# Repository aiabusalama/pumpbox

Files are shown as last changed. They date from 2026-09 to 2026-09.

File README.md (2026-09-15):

# REISBOT Pump Guard

A small box that keeps a solar-powered water pump alive. Rust on a Raspberry Pi Zero W.

## The problem

The pump is a 138 V, 1.5 kW DC brushless submersible (110–150 V range, 11 A max). Its own controller card
is destroyed above 150 V. The array is three GSE-HC455 panels in series: 150.9 V open-circuit at 25 °C, and
climbing toward 165 V on a cold morning — exactly the voltage present at sunrise, before any current flows.
That killed the first controller card. The second time it could not be repaired.

## What the box does

- Watches the array voltage and current every few milliseconds (PZEM-017 over RS-485).
- Keeps the contactor open until the array has settled inside the safe window (95–145 V), and drops it
  again on over-voltage, under-voltage, over-current, a dry well, or loss of contact with the meter.
- Waits, re-checks that the voltage is steady (about 15 s), and restarts by itself.
- Runs the pump from the water levels: a level relay in the well, another in the tank.
- Shows everything on a 20×4 LCD, one status light (blinking = ready, solid = running, two flashes =
  too high, three = too low) and a phone dashboard over its own Wi-Fi hotspot.

## Parts

| Part | Role |
|---|---|
| Raspberry Pi Zero W | the brain, runs `pumpd` |
| PZEM-017 + 50 A shunt | volts, amps, watts on the pump line |
| Schneider contactor | switches the 150 V DC pump line |
| 5 V relay module | drives the contactor coil from the Pi |
| HLK-10M24 | 143 V → 24 V for the contactor coil |
| 5 V / 3 W supply | the Pi |
| 12 V converter | feeds the two level relays |
| 2 × SSRC-04 level relays | well and tank levels — sold for 220 V AC, bypassed to run on 12 V DC (two jumper wires) |
| 20×4 I²C LCD, mode switch, START / STOP buttons | the front panel |

## Repo layout

- `rust/` — `pumpd`, the controller: state machine, PZEM-017 meter, front panel, LCD, watchdog, fail-safe,
  web dashboard. `rust/src/bin/` holds two bench tools (`failprobe`, `wdtest`).
- `kicad/level/` — the level-sensor board (schematic, PCB, etch transfers, drill file, wire-link map); `kicad/render/`
  shows the finished board; `kicad/BOM.txt` is the sourcing list.
- `hotspot/` — the Pi's Wi-Fi hotspot: setup script, captive-portal responder, watchdog units.
- `fritzing/`, `qet/` — wiring sketch and electrical diagram.
- `docs/` — enclosure layout and wiring pages; `DESIGN.md` and `BUILD.md` — design notes and build guide.

## Disclaimer

This is a personal hobby project, built for one farm and shared as-is. It is not a product, it is not certified,
and it is not affiliated with or endorsed by any employer or manufacturer. It switches 150 V DC, which can injure
or kill: if you copy any of it, you take full responsibility for your own installation, and you should have a
qualified electrician check it. No warranty of any kind — see the licence.

## Licence

MIT

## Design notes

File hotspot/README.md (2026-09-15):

# Field hotspot

The pump box has to be commissioned at a site with **no router, no WiFi and no
usable mobile data**, with **only a phone**. Nothing in the rest of this repo
gets you a network there: `BUILD.md` assumes the Pi already joined a WiFi you
control and tells you to browse to `http://<pi-address>:8080`. At the field
site there is no such address and no way to discover one.

This directory makes the Pi **its own access point**, so the phone joins the
box directly.

```
    SSID       PumpBox
    PASSWORD   ReisLandPump2026
    DASHBOARD  http://192.168.4.1:8080/
```

Change any of that in [`hotspot.conf`](hotspot.conf) and re-run the script.

---

## Run it

**At home, over SSH, before the trip.** It needs internet once, for
`dnsmasq-base`.

```bash
cd ~/automations/pump/hotspot     # wherever deploy.sh put the repo
sudo bash setup-hotspot.sh
```

Then the only test that counts:

```bash
sudo reboot
# ...with your home router powered OFF...
sudo bash setup-hotspot.sh --status
```

| Command | Effect |
|---|---|
| `sudo bash setup-hotspot.sh` | configure and activate |
| `sudo bash setup-hotspot.sh --status` | report only, changes nothing, no root needed |
| `sudo bash setup-hotspot.sh --no-activate` | configure, apply on next reboot |
| `sudo bash setup-hotspot.sh --undo` | remove everything it installed |

It is idempotent. Re-running converges the machine rather than stacking
changes, so it is safe to run after editing `hotspot.conf`, and safe to run on
a box you are not sure about.

If you run it **while connected over the hotspot itself**, it notices (your
`SSH_CONNECTION` source is in the AP subnet) and defers activation rather than
cutting the session out from under you. Reboot to apply.

---

## What it does

**One NetworkManager profile.** Not hostapd + dnsmasq. Bookworm made
NetworkManager the only network stack on every image including Lite — `dhcpcd`
and `/etc/network/interfaces` are gone, so the static-IP half of every older
tutorial silently does nothing, and NM keeps managing `wlan0` and fights
hostapd for it. NM's AP mode drives the same wpa_supplicant code path and
spawns its own scoped dnsmasq for DHCP. One profile, no second daemon stack,
which matters on a 512 MB single core.

Specifically:

| | |
|---|---|
| **Packages** | Installs `dnsmasq-base`, `iw`, `rfkill`. Holds and disables the full `dnsmasq` **daemon** — it binds `:53` system-wide and collides with the private instance NM spawns for shared mode. |
| **Regulatory domain** | Three ways: `/etc/modprobe.d/pump-ap-regdom.conf`, `raspi-config nonint do_wifi_country`, and `pump-ap-regdom.service` re-asserting at boot before NM. Pi OS keeps WLAN rfkill soft-blocked until a country is set, and the failure is silent — the profile activates "successfully" and no SSID is ever transmitted. |
| **Competing profiles** | Sets `autoconnect no` on every *other* WiFi profile, by enumerating real names. Raspberry Pi Imager's WiFi customisation creates one called **`preconfigured`**, so guides that say "set your home profile to autoconnect no" name something that does not exist — and the bench rehearsal then quietly runs on home WiFi, which is the one thing it exists to disprove. |
| **AP profile** | `pump-ap`: AP mode, band bg, fixed channel, `ipv4.method shared`, `192.168.4.1/24`, IPv6 off, `autoconnect-priority 100`, `autoconnect-retries 0` (retry forever). |
| **Watchdog** | `pump-ap-watchdog.timer` every 2 min. Brings the AP up **only if `wlan0` has no active connection**, so it recovers a dead AP without yanking you off home WiFi mid-`apt` at the bench. |
| **Boot diagnostics** | `pump-ap-diagnostics.service` appends the network state to `/boot/firmware/pumpnet.log` on every boot. |
| **Captive portal** | Answers Android/Apple connectivity probes so the phone stops nagging and stops routing your request out the cellular interface. Own process, port 80. |
| **Boot speed** | Disables `NetworkManager-wait-online.service`, which can stall boot 45 s waiting for a network that will never exist at the site. |

### Why `192.168.4.1` and not NM's default `10.42.0.1`

Turkish carriers hand out CGNAT addresses inside RFC1918 `10.0.0.0/8`. A phone
holding a `10.x` cellular route can send `10.42.0.1` out the LTE interface
instead of the WiFi one, and the symptom is indistinguishable from a dead Pi.
`192.168.4.0/24` has no such overlap.

If you have seen `10.42.0.1` written on an earlier version of the field card or
the lid label, **it is wrong** — fix it before printing.

---

## On the phone

**In this order. The first step is not optional.**

1. **Airplane mode ON, then WiFi back ON.**
2. Join `PumpBox`.
3. Browser: **`http://192.168.4.1:8080/`** — type the `http://`.

Airplane mode first is the guarantee, not a superstition. Android probes
`http://connectivitycheck.gstatic.com/generate_204` over a candidate network;
with no upstream that fails, the network is marked unvalidated, and the failure
mode is usually **not** "WiFi disconnects" — it is "WiFi stays connected but
the browser's request to the Pi leaves via LTE and dies." With the cellular
radio off there is no alternative route and the whole class of problem is gone.
There is no usable data at the site anyway.

Also set once, at home:

- **Private DNS → Off.** A DoT hostname makes the phone bypass the Pi's dnsmasq
  entirely.
- **Adaptive Connectivity / "switch to mobile data automatically" → Off.** Name
  varies by vendor. This is the setting that actively drops a no-internet WiFi.
- When "This network has no internet access. Stay connected?" appears, tick
  **"Don't ask again for this network"** and tap **Yes**.

Type the `http://`. Chrome hands a bare `192.168.4.1:8080` to the search engine
often enough to matter, and the search fails because there is no internet.

### Do not rely on `raspberrypi.local`

`BUILD.md` offers it "if your phone supports mDNS". Android has never reliably
resolved `.local` from a browser. The AP address is static by construction, so
mDNS buys nothing and can only produce a confusing failure at the worst moment.

### Print this for inside the lid

```
SSID       PumpBox
PASSWORD   ReisLandPump2026
DASHBOARD  http://192.168.4.1:8080/
```

Add two QR codes on the same A4 sheet — one
`WIFI:T:WPA;S:PumpBox;P:ReisLandPump2026;;` (the Android camera joins from it,
no typing) and one `http://192.168.4.1:8080/`. Typing a 16-character password
on a phone in field sunlight eats twenty minutes.

---

## Verifying the AP is up

### From the box, with a shell

```bash
sudo bash setup-hotspot.sh --status
```

The four lines that matter:

| Line | Good | Bad |
|---|---|---|
| regulatory domain | `country TR:` | `country 00: DFS-UNSET` → **AP transmits nothing** |
| rfkill | both blocks `no` | `Soft blocked: yes` → no country set |
| Active on wlan0 | `pump-ap` | *nothing active* → AP is down |
| Attached phones | `1` after you join | `0` → association or DHCP failed |

### From the phone, with no app and no shell

**Look at the phone's own IP.** Settings → WiFi → `PumpBox` → details.

- **`192.168.4.x`** — radio *and* DHCP both work. Any remaining problem is the
  web service or Android routing (go back and do airplane mode).
- **`169.254.x.x` or no address** — association succeeded, **DHCP failed**.
  That is `dnsmasq-base` missing or NM's dnsmasq refusing to start. This is the
  only way to see that failure without a shell, and it is the single most
  likely silent one.
- **Not in the WiFi list at all** — the regulatory domain, almost certainly.

### From the LCD

Currently: **you cannot.** See the known-issues section below — the LCD will
show a blank address line even when the AP is perfectly healthy. That is a bug
in `pump_control.py`, not in this directory, and it is not fixed here.

---

## Undo

```bash
sudo bash setup-hotspot.sh --undo
```

Removes the units, the AP profile, the dnsmasq drop-in, the modprobe file and
the installed helpers, and restarts NetworkManager.

It deliberately does **not** re-enable your other WiFi profiles — it has no way
to know which of them you wanted autoconnecting. Put your home network back
with:

```bash
nmcli connection modify preconfigured connection.autoconnect yes
```

### Getting on home WiFi temporarily without undoing anything

At the bench, to run `apt` or `deploy.sh`:

```bash
sudo touch /run/pump-ap-inhibit          # stop the watchdog reclaiming the radio
sudo nmcli connection up preconfigured   # or whatever `nmcli con show` calls it
```

`/run` is tmpfs, so **any reboot clears the inhibit and returns to the AP.**
There is no state in which you can strand yourself. To come back without
rebooting:

```bash
sudo rm /run/pump-ap-inhibit
sudo nmcli connection up pump-ap
```

---

## When the phone will not associate

Work down this list. Each step is one edit to `hotspot.conf` and a re-run.

1. **`PMF="1"`** (the shipped default). NM's default resolves to
   PMF-*optional* for `wpa-psk`, so the AP advertises 802.11w-capable.
   brcmfmac's AP path handles 802.11w poorly and a failed negotiation surfaces
   on Android as **"incorrect password"**. This is the leading suspect.
2. **`STRICT_CIPHERS="no"`** (the shipped default) leaves `proto`, `pairwise`
   and `group` unset, which is what NetworkManager's own documentation
   recommends for maximum compatibility. Try `"yes"` (WPA2-AES pinned) if
   loose fails — the field evidence is genuinely contradictory, one Raspberry
   Pi forum thread reports Android working only after *removing* the pinning
   and an Arch thread reports the exact opposite.
3. **`CHANNEL`** → try `1` or `11`.
4. **`PSK=""`** — an open, unencrypted AP. Last resort, and a legitimate one:
   the box is on private family land and its only exposed control sits behind a
   143 V DC contactor. An unencrypted dashboard beats an unreachable one.

> There is a published report of a **Zero W on 32-bit Bookworm** whose
> NetworkManager AP refuses Android with "password incorrect" while Windows and
> Linux connect fine. **Test with the actual phone you are taking.** A laptop
> associating proves nothing about this failure.

## Do not run Trixie on this board

Pi OS 13 (Trixie) **cannot bring up a WPA-protected nmcli hotspot on an
original Pi Zero W.** Activation dies with `802.1X supplicant took too long to
authenticate` and the kernel logs `key setting validation failed` from
brcmfmac. Upstream issue [raspberrypi/linux#7247][7247] is open with no
workaround. Open hotspots still come up; adding `wpa-psk` kills it.

Use **Raspberry Pi OS 12 (Bookworm) Lite, 32-bit**. The Zero W is ARMv6 and
cannot run a 64-bit image at all. Confirm with `cat /etc/os-release` →
`VERSION_ID="12"`. The script warns if it sees anything else.

Do not `apt full-upgrade` across a release before the trip. If you want to be
strict about it, Bookworm's own security pocket can still move the two packages
implicated in that bug:

```bash
sudo apt-mark hold network-manager wpasupplicant
```

The script does **not** do this for you — it blocks security updates, and that
is your call, not the script's.

## Do not run AP and home WiFi at the same time

One radio, one channel. The AP gets forced onto whatever channel the router
picked; throughput roughly halves; and brcmfmac's AP+STA combination on the
BCM43438 is the least-exercised path in the driver — on the same board that
already cannot complete a plain WPA hotspot on Trixie. You would be stacking
your only access on the flakiest available configuration, to gain nothing: at
the field site there is no other network for the client half to join.

Two profiles, AP always wins a reboot. That is what the script sets up.

---

## Phone-only recovery, when the AP is dead

**Triage on the LCD first**, because it splits the problem cleanly:

- **LCD blank** → power, boot or SD card. Not a network problem.
- **LCD shows STANDBY with live volts** → the controller is alive and
  protecting. This is *purely* a WiFi problem. **The pump is safe. You can stop
  here and tune the dashboard another day.** `BUILD.md` Stage 6 needs 2–3 days
  of history before dry-run tuning is meaningful, so the dashboard is genuinely
  not needed on day one. The real risk at this point is you poking at a working
  protection box.

Then, in order:

1. Wait a full 90 s. NM can be slow to bring up AP mode on this board.
2. Power-cycle once. The watchdog retries every 2 minutes after that.
3. Phone: forget the network, rescan. Confirm airplane mode is on.
4. **Swap to the spare SD card.** This is the recovery mechanism.
5. Only then, power down and read `/boot/firmware/pumpnet.log` on the phone via
   an OTG card reader, to learn *which* card to blame.

### Why the log is read-only and there is no editable config on the boot partition

An earlier plan for this box proposed a `/boot/firmware/pumpnet.conf` you could
edit from the phone to fix the AP in the field. **That is not a phone
procedure.** Executing it costs: open the DC breaker (pump stops), unscrew the
IP65 lid, unplug the Pi from the LM2596 and the USB-RS485 cable, extract a
microSD that protrudes about a millimetre from a Zero W's friction slot, plug
in an OTG reader, edit, reinsert, reassemble, re-energize — and it is
edit-reboot-repeat, so **every hypothesis costs a full disassembly cycle.**

Worse, a Pi OS card has a FAT32 boot partition and an ext4 root, and some
Android builds respond to that by offering to "fix" the **corrupted USB drive**
— tapping it formats the card you were trying to rescue.

So: reading the log **once** is a plausible field action and is supported. The
fix for a dead AP is **the spare SD card**, not an editor. Prepare two
identical cards and verify both boot before you leave. You cannot write a disk
image from stock Android; if both cards fail on site, the trip is over.

If you do want an in-field AP override, make it **physical** — a jumper on a
spare GPIO, read at boot, forcing an open no-password AP on channel 6. That
bypasses every failure a config file guards against (wrong PSK, wrong channel,
wrong regdomain) without opening anything. Not implemented here.

### The one thing on the boot partition you *can* usefully change from a phone

The regulatory domain is also settable as a kernel parameter, by appending this
to the single line in `/boot/firmware/cmdline.txt`:

```
cfg80211.ieee80211_regdom=TR
```

`cmdline.txt` is on the FAT partition, so it is reachable over an OTG reader,
and a missing country code is the highest-probability AP failure. Worth writing
on the lid label next to the SSID.

**Caveat, stated plainly:** this script does *not* write that line, because
whether a kernel-command-line module parameter is honoured for `cfg80211` when
it loads as a module is exactly the sort of thing that must be checked on the
hardware rather than assumed. The script uses `/etc/modprobe.d` and a boot-time
`iw reg set` instead, both of which are unambiguous. Treat the `cmdline.txt`
line as an unverified emergency lever: it will not hurt, and it may help.

---

## Known issues in the rest of the repo that this directory does not fix

These are real, they bite specifically in AP mode, and they are **not** touched
here because this task was scoped to the hotspot. Fix them before the trip.

**1. The LCD will never show you the address.** `pump_control.py:22-31`:

```python
s.connect(("192.0.2.1", 1))       # TEST-NET-1, never routed
ip = s.getsockname()[0]
```

That works by asking the kernel which source address a route to an arbitrary
destination would use. `ipv4.method=shared` installs **only** the on-link
`192.168.4.0/24` route and **no default route** — correctly, there is no
upstream. So `connect()` fails with `ENETUNREACH`, `except OSError` returns
`None`, and the LCD's address line renders as `""` or `waiting for band`. You
stand at the box with a working hotspot and a screen telling you nothing.

Read the interface instead of the routing table — `SIOCGIFADDR` via `fcntl`, or
`ip -4 -o addr show wlan0`. Note that `install.sh:70` already uses the AP-safe
incantation (`hostname -I`); the broken one is in `pump_control.py`. The fix is
already in this repo, in the wrong file.

**2. The address is read once, at startup.** `pump_control.py:44` calls
`local_ip()` in `App.__init__`. On a cold boot the protection service easily
wins the race against NetworkManager, caches `None`, and never re-checks for
the rest of the day. Re-read it on a slow cadence — every ~10 s from the main
loop, into a cached string, never raising into the loop.

**3. A dashboard that cannot bind permanently stops the pump.**
`pump_control.py:45` calls `web.start(self.controller)` unguarded, and
`web.py:285` binds `0.0.0.0:8080`. If that raises — a lingering process after a
crash-restart, say — it propagates out of `App()`, `main()` returns 1, and
systemd's `Restart=always` retries every 5 s forever with the contactor open.
Wrap it:

```python
try:
    self.server = web.start(self.controller)
except OSError as e:
    log(f"dashboard unavailable: {e}")
    self.server = None
```

and make `shutdown()` tolerate `self.server is None`.

**4. Do not add `iw dev wlan0 station dump` to the control loop.** If you add a
client count to the LCD, read the lease files
(`/var/lib/NetworkManager/dnsmasq-*.leases`) — O(1), non-blocking. A subprocess
inside a 0.5 s loop on a single-core 512 MB board stalls `controller.update()`
and blinds the protection for its duration. If you must shell out, do it on the
web thread.

**5. Leave `pump-protection.service` at `After=network.target`.** Do not add
`Wants=`/`Requires=NetworkManager.service` or `network-online.target`. The pump
must come up on a box whose radio is dead. The script asserts this on every
run and refuses to finish if something has added such a line.

---

## Nothing here has been run on hardware

The Pi is not wired yet. Be precise about what that means.

**Verified off-hardware, on the workstation:**

- Every property in the profile is accepted by `nmcli --offline connection add`
  (nmcli 1.50) and emits the intended keyfile. Every property used dates to
  nmcli ≤ 1.4, so Bookworm's 1.42 accepts it.
- Clearing `proto`/`pairwise`/`group` with `""` produces a keyfile with those
  keys absent; empty `key-mgmt` produces one with no `[wifi-security]` section
  at all. Both compatibility fallbacks are real.
- `man nmcli` EXIT STATUS: **3 = timeout, 4 = connection activation failed.**
  Widely copied recipes have these swapped and mark a real activation failure
  as success. `pump-ap-ensure.sh` maps them correctly.
- `portal-responder.py`: 204 on `/generate_204` and `/gen_204` with no
  `Content-Length` (RFC 7230), the exact Apple success body on
  `/hotspot-detect.html`, 302 to the dashboard for everything else, HTTP/1.1
  keep-alive across all three, and a second instance losing port 80 exits 0
  instead of restart-looping.
- `pump-ap-ensure.sh` decision paths: already-up, another-connection-owns-the
  interface, inhibit-file, activation-failure. All behave.
- `pump-ap-diagnostics.sh` produces a useful log and caps its own size.
- All shell files pass `bash -n`; the Python compiles.

**NOT verified, and only the hardware can settle it:**

| | |
|---|---|
| **That an Android phone associates at all** | The highest-risk item by a distance. There is a published report of exactly this stack — Zero W, 32-bit Bookworm, NM AP, WPA2 — refusing Android with "password incorrect". **Test with your phone, not a laptop.** Do this *before* the cold-boot rehearsal; everything else is downstream of it. |
| That `brcmfmac` starts AP mode on this Zero W at all | Widely reported working on Bookworm. Not observed by me on this board. |
| That NM autoconnects the AP on a cold boot | The whole reason the watchdog timer exists. |
| That `raspi-config nonint do_wifi_country` persists on Bookworm | Check `iw reg get` **after a reboot**, not before. The modprobe file and the boot service are there because this is uncertain. |
| That `cfg80211.ieee80211_regdom=` on the kernel command line is honoured for a loadable `cfg80211` | Documented above as an unverified emergency lever, deliberately not used by the script. |
| That `ipv4.method shared` serves DHCP with no upstream link | Reasoned from NM's shared-mode design. Confirm by joining and reading the phone's own IP. |
| Whether Android accepts a plain-HTTP 204 as validation | Modern Android runs an HTTPS probe alongside, which cannot be satisfied without a trusted certificate. Treat the portal as *reduces the nag*, not a guarantee. **Airplane mode is the guarantee.** |
| Exact DHCP pool bounds NM picks in `192.168.4.0/24` | Does not matter — you never need the phone's address, only its prefix. |
| Whether `/var/lib/NetworkManager/dnsmasq-wlan0.leases` is the exact path | Globbed rather than hardcoded, so a different filename still counts. |
| That the OTG card reader mounts this card on this phone | Test the exact reader/phone/card combination at home. |
| The AP's cost on a 512 MB single core already running the 0.5 s poll loop | Watch for control-loop lag with a phone attached. |

**Rehearse these two at the bench, in this order. Everything else in this
document is recoverable in the field; these are not:**

1. **Associate your actual Android phone**, in airplane mode, and load
   `http://192.168.4.1:8080/`.
2. **Cold-boot the box five times with the router powered off** and confirm
   `--status` reaches `192.168.4.1` every time.

[7247]: https://github.com/raspberrypi/linux/issues/7247

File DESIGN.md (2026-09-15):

# Pump Controller — Design

## What the user actually needs

Someone standing at the shed door wants to know three things in under a second:

1. **Is water flowing?**
2. **If not, why not, and will it fix itself?**
3. **Can I do something about it right now?**

Everything below serves those three questions.

---

## Modes

The operator chooses how much autonomy the controller has.

| Mode | Behaviour | When you'd use it |
|---|---|---|
| **AUTO** | Starts the pump whenever conditions are safe. Restarts after transient faults. | Normal running. Set once, forget. |
| **MANUAL** | Waits at READY. Only a button press or dashboard command starts it. | Filling a specific tank, testing, working on the well. |
| **OFF** | Contactor held open. Nothing starts it. | Maintenance. Physically safe to work. |

Mode persists across reboots — a power cut must not silently re-arm a pump
you deliberately stopped.

---

## States

```
                    ┌──────────────────────────────────────┐
                    │                                      │
   power on         ▼                                      │
      │        ┌─────────┐   conditions bad          ┌──────────┐
      └───────▶│ WAITING │◀──────────────────────────│ RUNNING  │
               └────┬────┘                           └──────────┘
                    │ conditions good, stable              ▲
                    ▼                                      │
               ┌─────────┐    AUTO: automatic              │
               │  READY  │────────────────────────────────-┘
               └────┬────┘    MANUAL: button or dashboard
                    │
      any fault     │
      ┌─────────────┴──────────────┐
      ▼                            ▼
 ┌─────────┐                 ┌──────────┐
 │ TRIPPED │                 │ LOCKOUT  │
 └─────────┘                 └──────────┘
  recovers when               dry well - waits
  conditions return           45min / 2h / 8h
```

| State | Meaning to the operator | Contactor |
|---|---|---|
| `WAITING` | Conditions not safe yet. Voltage out of band. | open |
| `READY` | Everything is fine. In MANUAL, waiting for you. | open |
| `STARTING` | Confirming stability before closing. ~15 s. | open |
| `RUNNING` | Water is flowing. | **closed** |
| `TRIPPED` | Something went wrong. Will retry when safe. | open |
| `LOCKOUT` | Well is dry. Resting so it can recover. | open |
| `FAULT` | Cannot read the meter. Refusing to run blind. | open |
| `OFF` | You switched it off. | open |

`READY` exists so MANUAL mode has somewhere to sit: everything is safe, the
pump could start, it is waiting for a human. Without it, MANUAL and WAITING
would be indistinguishable on the display.

---

## Physical controls

Three buttons and an LED. The shed is not always in phone range, and gloves
do not work on touchscreens.

| Control | Short press | Long press (2 s) |
|---|---|---|
| **START / STOP** | MANUAL: start the pump. RUNNING: stop it. | — |
| **MODE** | Cycle AUTO → MANUAL → OFF | — |
| **RESET** | Clear a trip and retry now | Clear a dry-run lockout |

**Status LED** — visible from the doorway:

| Pattern | Meaning |
|---|---|
| Solid green | Running |
| Slow green pulse | Ready, waiting for you |
| Slow amber pulse | Waiting for conditions |
| Fast amber blink | Dry-run lockout |
| Solid red | Tripped |
| Fast red blink | Meter fault |
| Off | Mode is OFF |

---

## Display

Four lines, 20 characters. Line 1 is the answer; lines 2–4 are the detail.

**Running** — the good case:
```
RUNNING        AUTO
  126.4V   10.8A
  1367W    4h 12m
today 8.4kWh  ▓▓▓▓
```

**Ready, manual** — the pump is waiting for you:
```
READY - PRESS START
  128.1V    0.0A
all conditions ok
mode MANUAL
```

**Waiting** — tell them what for, and how close:
```
WAITING
  152.3V   too high
need under 138V
warming up  ▓▓▓░░░░
```

**Dry lockout** — the one that needs explaining:
```
WELL RECOVERING
dry run detected
retry in 38 min
strike 1 of 3
```

**Tripped** — what happened and what now:
```
STOPPED - OVERVOLT
was 147.2V at 09:14
now 131.8V  ok
retrying in 12s
```

Every screen answers "why" without the operator needing the manual.

---

## Dashboard

Same information, more of it, from a phone.

- **Live tile** — state, volts, amps, watts, updating every second
- **Mode switch** — AUTO / MANUAL / OFF, one tap
- **Start / Stop** — big, only enabled when the action is valid
- **Today** — energy, run time, number of starts
- **History** — 24 h chart of voltage and current
- **Events** — what tripped, when, at what reading
- **Settings** — thresholds, validated before saving

---

## Safety invariants

These hold regardless of mode, settings, or dashboard state:

1. The contactor is **normally open**. Losing power, the process, or the
   relay drops the pump.
2. Voltage limits are **never** overridden by mode. MANUAL start is refused
   if conditions are unsafe — the button does nothing and says why.
3. Losing the meter for more than 3 seconds **stops the pump**. Running
   blind is never safe.
4. A dry-run lockout survives restart. It is written to disk.
5. Mode survives restart. A power cut does not re-arm a pump someone
   deliberately switched off.

---

## Observability

Designed to be diagnosed from a phone, over a slow link, weeks later.

- **`/metrics`** — Prometheus format: state, volts, amps, watts, energy,
  trip counts by reason, uptime, meter error rate
- **Structured logs** to journald, one line per state change with the
  readings that caused it
- **`history.csv`** — one row per minute, rotated weekly
- **Heartbeat file** touched every loop; a systemd timer restarts the
  service if it goes stale, catching a wedged process that systemd would
  otherwise consider healthy

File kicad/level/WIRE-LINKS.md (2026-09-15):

# Wire links — REISBOT level board

75 insulated wires, 3.6 m total.

These are the connections one side of copper could not carry. Each is
an insulated wire lying on the **component side**, with both ends
soldered from the copper side along with everything else. Fit them
**before** the parts — several run under IC bodies.

Print `2-wire-links-map.pdf` and tick them off.

| # | Net | From | To | Length |
|---|-----|---|----|---|
| 1 | +3V3 | D24.2 | U1.2 | 69 mm |
| 2 | +3V3 | D5.2 | U8.16 | 40 mm |
| 3 | +3V3 | C13.1 | U4.16 | 26 mm |
| 4 | +3V3 | R31.1 | RV1.1 | 26 mm |
| 5 | +3V3 | U1.2 | C4.1 | 15 mm |
| 6 | +3V3 | R37.1 | U6.3 | 11 mm |
| 7 | +3V3 | U8.16 | C13.1 | 5 mm |
| 8 | +5V | R80.1 | R1.1 | 40 mm |
| 9 | +5V | R88.1 | U3.9 | 18 mm |
| 10 | +5V | R88.1 | R89.1 | 13 mm |
| 11 | +5V | R85.1 | R84.1 | 13 mm |
| 12 | COIL_V | U7.9 | J4.1 | 163 mm |
| 13 | DET | D3.2 | U3.5 | 92 mm |
| 14 | EXC | C7.2 | J11.1 | 24 mm |
| 15 | EXC_OK | R68.2 | U8.4 | 86 mm |
| 16 | GND | R65.2 | U6.12 | 28 mm |
| 17 | GND | R20.2 | R19.2 | 20 mm |
| 18 | GND | C12.2 | R55.2 | 15 mm |
| 19 | GND | R47.2 | Q2.3 | 13 mm |
| 20 | GND | R19.2 | C8.2 | 12 mm |
| 21 | GND | U3.2 | RV1.3 | 12 mm |
| 22 | GND | C3.2 | C4.2 | 11 mm |
| 23 | GND | C9.2 | U4.15 | 11 mm |
| 24 | GND | U2.1 | C11.2 | 7 mm |
| 25 | GND | U5.8 | R46.2 | 7 mm |
| 26 | GND | C13.2 | U4.8 | 7 mm |
| 27 | GND | R73.2 | R71.2 | 6 mm |
| 28 | L1 | D10.1 | U4.11 | 74 mm |
| 29 | L1 | SW1.1 | U5.6 | 43 mm |
| 30 | L2 | U4.12 | D11.1 | 71 mm |
| 31 | L2 | R32.2 | SW1.2 | 30 mm |
| 32 | L3 | D12.1 | U4.13 | 68 mm |
| 33 | L4 | R34.2 | D13.1 | 62 mm |
| 34 | L4 | R34.2 | SW1.4 | 31 mm |
| 35 | L5 | R35.2 | U4.3 | 71 mm |
| 36 | L5 | R35.2 | U3.15 | 32 mm |
| 37 | L6 | R36.2 | U4.4 | 58 mm |
| 38 | L6 | R36.2 | D15.1 | 42 mm |
| 39 | L6 | SW1.6 | R36.2 | 32 mm |
| 40 | L7 | R37.2 | U4.5 | 70 mm |
| 41 | L7 | SW1.7 | U3.13 | 34 mm |
| 42 | L7 | R37.2 | D16.1 | 24 mm |
| 43 | L8 | SW1.8 | U3.12 | 34 mm |
| 44 | L8 | SW1.8 | R38.2 | 33 mm |
| 45 | L8 | U3.12 | D17.1 | 24 mm |
| 46 | LEDW1 | R66.1 | D23.1 | 75 mm |
| 47 | LED_EXC | R47.1 | D7.1 | 151 mm |
| 48 | LED_PWR | R45.1 | D5.1 | 146 mm |
| 49 | OSC_T | U2.2 | U2.6 | 8 mm |
| 50 | P2 | R12.1 | J2.3 | 68 mm |
| 51 | P3 | R13.1 | J2.4 | 69 mm |
| 52 | P7 | R17.1 | J2.8 | 67 mm |
| 53 | P8 | R18.1 | J2.9 | 59 mm |
| 54 | PUMP | D6.2 | U8.14 | 47 mm |
| 55 | PUMP_N | R50.1 | U5.2 | 59 mm |
| 56 | PUMP_N | U8.3 | R50.1 | 54 mm |
| 57 | PUMP_OUT | R70.1 | J4.2 | 133 mm |
| 58 | RHI_SET | RV1.2 | U3.6 | 15 mm |
| 59 | SCLK | U8.2 | J1.5 | 85 mm |
| 60 | SDATA | J1.6 | U4.9 | 93 mm |
| 61 | SLOAD | U8.1 | J1.4 | 85 mm |
| 62 | TGT_HI | U5.4 | R43.2 | 29 mm |
| 63 | U8Q7 | U8.9 | U4.10 | 31 mm |
| 64 | VLV_EN | SW2.3 | U7.2 | 24 mm |
| 65 | VLV_GATE | SW2.2 | R50.2 | 27 mm |
| 66 | VLV_OUT | R72.1 | J4.3 | 122 mm |
| 67 | VLV_SNS | R73.1 | R72.2 | 26 mm |
| 68 | W1 | J11.2 | R51.1 | 92 mm |
| 69 | W2 | R52.1 | J11.3 | 86 mm |
| 70 | W3 | R53.1 | J11.4 | 86 mm |
| 71 | WDET | R55.1 | U6.8 | 61 mm |
| 72 | WELL1 | R60.2 | U8.11 | 53 mm |
| 73 | WELL2 | U8.12 | R66.2 | 65 mm |
| 74 | WELL3 | R67.2 | U8.13 | 47 mm |
| 75 | WELL_OK | SW2.1 | R58.2 | 53 mm |

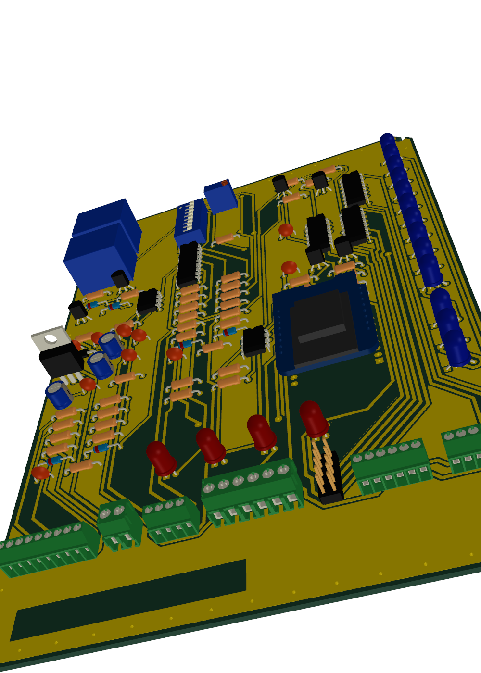
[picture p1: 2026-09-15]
kicad/render/final_iso.png

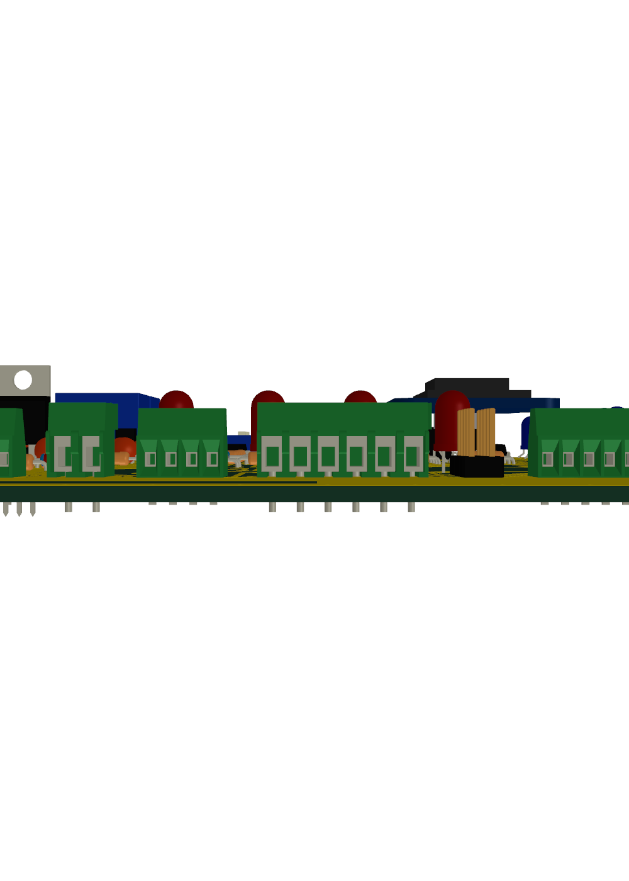
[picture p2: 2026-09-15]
kicad/render/final_top.png

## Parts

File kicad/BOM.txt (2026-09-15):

REISBOT level board - cost reduced from 479 TL to 288 TL

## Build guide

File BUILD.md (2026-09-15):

# Solar Pump Protection — Build Guide

## Why

**Pump:** 138 V 1500 W DC brushless submersible, 11 A max, 110–150 V range.
Its controller card is destroyed above 150 V. It already self-protects below 110 V.

**Array:** 3 × GSE-HC455 in series. Voc 50.30 V each → **150.9 V at 25 °C**,
climbing toward 165 V on a cold morning. That voltage is present whenever no
current is flowing — which is exactly the situation at sunrise, before the pump
starts. That is what killed the first pump.

The contactor stays open until the array has settled into a safe band, and
drops out again on overvoltage, undervoltage, overcurrent, a dry well, or loss
of contact with the meter.

---

## Shopping list

### Already have

| Item | Note |
|---|---|
| Raspberry Pi Zero W | brain, WiFi |
| PZEM-017 + 50 A shunt | volts, amps, watts |
| 20×4 I²C LCD | local display |
| 5 V relay module | drives the contactor coil |
| HLK-10M24 | 143 V → 24 V |
| HLK-PM01 | now spare |
| PA003-4 terminals ×3 | 143 V bus |
| LP1K0901BD contactor | the switch |
| Soldering iron | for the perfboard |

### To buy — motorobit (~₺343)

| Item | Link | ₺ |
|---|---|---|
| **MAX485 TTL-RS485** | [motorobit](https://www.motorobit.com/ttl-rs485-seri-donusturucu-karti-max485) | 33 |
| 5×7 cm perfboard ×2 | [motorobit](https://www.motorobit.com/urun/5x7cm-epoxy-cift-tarafli-delikli-plaket) | 50 |
| 40-pin F-F jumpers | [motorobit](https://www.motorobit.com/40pin-20cm-female-female-jumper-cable) | 40 |
| M6 ring lugs ×4 | [motorobit](https://www.motorobit.com/jg6-6-m6-skp-kablo-pabucu) | 40 |
| Ferrule set + crimper | [motorobit](https://www.motorobit.com/800-pieces-8-types-of-insulated-ferrule-set-cable-ferrule) | 180 |

### To buy — solardepo (~₺750)

| Item | Link | ₺ |
|---|---|---|
| DC fuse 16 A + 1000 V holder | [solardepo](https://www.solardepo.com/hegel-dc-1000v-20ka-kartus-yuvasi-hegel-dc-20a-1000v-kartus-sigorta) | 150 |
| DC breaker 16 A 550 V | [solardepo](https://www.solardepo.com/pantec-dc-16a-550v-devre-kesici) | 250 |
| DC SPD Type 2 | [solardepo](https://www.solardepo.com) | 350 |

> The SPD **must say DC**. An AC unit looks identical and fails dangerously
> on a DC line.

### To buy — local shops (~₺1,000)

| Item | Where | ₺ |
|---|---|---|
| LM2596 buck converter | electronics shop | 60 |
| Stick-on heatsink for the Pi | electronics shop | 20 |
| SD card, endurance grade | anywhere | 150 |
| 4 mm² solar cable + MC4 pair | [mundasolar](https://mundasolar.com/urun/4mm-solar-kablo/) | 430 |
| IP65 enclosure, room for the contactor | electrical supply | 400 |

**Total to buy: ~₺2,100**

---

## Stage 0 — Rewire the array to 3S1P

Free, and the single biggest safety gain.

| | 3S2P (6 panels) | 3S1P (3 panels) |
|---|---|---|
| Running voltage | ~143 V | **~126 V** |
| Margin below 150 V | 7 V | **24 V** |

Voc is 150.9 V either way — the controller handles that. But 126 V running
gives real margin and stops nuisance trips on cool days.

---

## Stage 1 — Prepare the Pi

On a fresh Raspberry Pi OS **Lite** install, with WiFi configured:

```bash
git clone <or copy> pump-protection
cd pump-protection
sudo bash install.sh
sudo reboot
```

The script installs dependencies, moves Bluetooth off the good UART, frees
the serial port from the login console, and registers the service.

### Why the UART matters

The Zero W gives the good PL011 UART to Bluetooth by default and leaves GPIO
with the mini-UART, whose baud rate drifts with CPU clock. That produces
intermittent Modbus CRC errors that look exactly like a wiring fault. The
install script adds `dtoverlay=disable-bt` to fix it.

---

## Stage 2 — Solder the board

Two boards keep the high and low voltage sides apart.

### Board A — power (143 V)

Solder onto one perfboard:

- 3 × PA003-4 terminal blocks
- HLK-10M24 (four PCB pins)
- LM2596 module

Wiring on the board:

```
Terminal 1  ──→ 143 V in from the fuse
            ├─→ HLK-10M24 AC pin 1
            ├─→ PZEM IN+ (flying lead)
            └─→ Terminal 3 (to contactor)

Terminal 2  ──→ 143 V negative
            ├─→ HLK-10M24 AC pin 2
            └─→ PZEM IN−
```

> **The HLK's input pins are labelled AC and have no polarity mark.** That is
> correct — there is a full-wave bridge rectifier behind them, so either pin
> can be your DC positive. The **output** pins `+Vo` / `−Vo` are marked and
> polarity there does matter.

### Board B — logic (5 V)

Solder the MAX485 module onto the second perfboard, or mount it on headers so
it can be swapped.

### Set the LM2596 before connecting anything

1. Feed it 24 V from the HLK-10M24
2. **Leave the output disconnected**
3. Turn the blue trimmer while watching a multimeter
4. Set to **5.1 V** — the slight excess covers cable drop
5. Only then wire it to the Pi

These boards ship set anywhere between 1.2 V and 35 V. Connecting an
unadjusted one to the Pi's 5 V pin destroys it instantly.

---

## Stage 3 — Bench test

**No high voltage.** Power the Pi from its normal USB supply.

### Wiring

```
MAX485          Pi Zero W (physical pin)
  RO      →     10   GPIO15 / RX
  DI      →      8   GPIO14 / TX
  DE ┐
  RE ┴   →      12   GPIO18
  VCC     →      2   5 V
  GND     →      6
  A / B   →     PZEM 4-pin header, A and B

LCD             Pi Zero W
  GND     →      9
  VCC     →      4   5 V
  SDA     →      3
  SCL     →      5

Relay           Pi Zero W
  VCC     →     17   (5 V)
  GND     →     14
  IN      →     11   GPIO17
```

DE and RE are tied together and driven from one pin — high to transmit, low
to receive.

### Run the checks

```bash
i2cdetect -y 1                          # find the LCD, usually 0x27 or 0x3F
sudo python3 test_hardware.py lcd       # four rows of text
sudo python3 test_hardware.py relay     # clicks every 1.5 s
sudo python3 test_hardware.py shunt     # sets the meter to 50 A
sudo python3 test_hardware.py meter     # reads 0.0 V unconnected
```

If `i2cdetect` shows a different address, change `LCD_I2C_ADDRESS` in
`config.py`.

**The shunt step is not optional.** The meter defaults to a 100 A shunt.
Yours is 50 A. Skip this and every current reading is double the truth —
which would break dry-run detection completely.

---

## Stage 4 — Wire the power side

**Breaker open. Verify 0 V with a meter before touching anything.**

DC arcs do not self-extinguish. Never separate a live 143 V connection by hand.

```
Panels (3S1P)
    │
    ├── DC breaker 16 A      manual isolation
    ├── DC fuse 16 A         1.56 × Isc of 11.48 A
    ├── DC SPD               surge → earth
    │
    ▼
Board A terminal bus ── 143 V
    │
    ├──→ PZEM IN+ / IN−            voltage sense, self-powered
    ├──→ HLK-10M24 → 24 V ─┬─→ LM2596 → 5.1 V → Pi, LCD, relay
    │                       └─→ relay COM
    │
    └──→ contactor pole 1 → pole 2 → pole 3 → Pump (+)

Pump (−) ──→ 50 A shunt ──→ Panels (−)

Relay NO ──→ coil A1
24 V GND ──→ coil A2
```

### Contactor — all three poles in series

```
143 V+ ──[1]─[2]──[3]─[4]──[5]─[6]── Pump+
        pole 1    pole 2    pole 3
```

The LP1K0901BD is rated for AC only. Three contact gaps in series break a
143 V DC arc that a single gap cannot. Chain them; do not use one pole.

### Shunt — in the negative line

The shunt's two **fat M6 bolts** carry the full pump current and belong in
the negative return. The two **small screws** are the sense tap and go to
PZEM SHUNT+ / SHUNT−. Crimp M6 ring lugs onto the pump cable for the bolts.

Swapping those roles destroys the meter.

---

## Stage 5 — First power-up

1. Close the breaker.
2. The contactor must stay **open**.
3. Watch the LCD — it shows STANDBY with the live voltage and the Pi's address.
4. Open that address in a browser on your phone: `http://<pi-address>:8080`
5. After 30 stable readings in the 118–138 V band, the contactor closes.
6. Running voltage should drop as the pump loads the array.

### Test the trip

With the pump running, open the breaker. Voltage collapses, the controller
trips on undervoltage, contactor opens. Close it again and it re-arms after
the settle period.

---

## Stage 6 — Tune dry-run detection

**Dry-run detection ships disabled.** Enabling it with guessed numbers will
either miss a dry well or stop a healthy pump.

### How it works

A pump moving water is a heavy load and drags the array down toward Vmpp.
Spinning in air it draws far less, so voltage drifts back up toward Voc.

| Condition | Volts | Amps |
|---|---|---|
| Pumping normally | ~126 V | ~11 A |
| Weak sun | ~115 V | ~6 A |
| **Running dry** | **~145 V ↑** | **~5 A ↓** |

Low current alone is ambiguous — weak sun looks similar. Dry running is the
only state where **voltage rises while current falls**, so both conditions
must hold together before it fires.

### The procedure

1. Run normally for **2–3 days** with dry detection off.
2. Download `history.csv` from the dashboard.
3. Find your real running numbers across the day — early morning, midday,
   late afternoon.
4. Set **Amps below** to about **half** your normal running current.
5. Set **While volts above** to about **10 V above** your normal running
   voltage.
6. Enable it and watch for a few days.

If it trips during a passing cloud, raise the voltage threshold or lengthen
the duration. If a genuinely dry well runs too long before tripping, lower
the current threshold.

### Escalating lockout

| Strike | Rest |
|---|---|
| 1st | 45 min |
| 2nd | 2 h |
| 3rd | 8 h — effectively until tomorrow |

A drawn-down well needs hours, not minutes. Retrying every five minutes wears
the pump for nothing. The dashboard has an override button for when you know
there is water.

Lockouts survive a restart — the state is written to disk, so a power cut
does not reset the counter.

---

## The dashboard

`http://<pi-address>:8080` from any phone or laptop on the WiFi.

- Live volts, amps, watts and state, refreshing every 2 seconds
- Every threshold editable from the browser — no SSH, no site visit
- Recent trip history with the reading that caused each one
- `history.csv` download for tuning
- Lockout override

Settings are validated before saving. It will refuse a high trip above 150 V,
or hysteresis bands that would make the pump chatter, and tells you why.

### Fix the address

The Pi's IP may change. Either reserve it in your router's DHCP settings, or
use `http://raspberrypi.local:8080` if your phone supports mDNS.

---

## Failure behaviour

Everything fails toward *pump off*:

| Failure | Result |
|---|---|
| Pi loses power | Relay opens, contactor drops |
| Script crashes | systemd restarts it; contactor open meanwhile |
| Meter stops replying | Trips after 6 failed reads — never runs blind |
| SD card corrupts | Pi does not boot, contactor never closes |
| Relay fails open | Pump stays off |
| 24 V supply dies | Coil de-energizes |
| WiFi drops | Protection unaffected; only the dashboard is lost |

The contactor is normally-open. The only way the pump runs is if the
controller is alive and actively holding the relay closed.

---

## Maintenance

```bash
sudo systemctl status pump-protection    # is it running
journalctl -u pump-protection -f         # live log
journalctl -u pump-protection --since today | grep OPEN    # today's trips
```

History and settings live in `/var/lib/pump-protection/`.

### Reducing SD wear

Once things are stable, consider enabling the read-only overlay filesystem
in `raspi-config` (Performance Options → Overlay File System). Root then runs
from RAM and the card is never written, making power cuts harmless. Remount
read-write temporarily when you need to change settings that persist.

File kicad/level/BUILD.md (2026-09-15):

# REISBOT Level Board — build notes

Tank and well level sensing with autonomous pump and valve control.
113 × 226 mm, 90 parts, **single-sided**, all through-hole.

## Built for your process

Toner transfer, acid etch, hand placement, **soldered from one side only**.
Everything below follows from that last constraint.

All the copper is on one face. The parts sit on the other face, their legs
come through the holes, and every joint — parts, terminals, wire links — is
made from the copper side. There is nothing to solder on the far face, and
nothing that needs reaching under a component body.

That cost 75 wire links on the previous revision. **The link count and the board size below have not been re-derived for this revision** — `place2.py` → `route_ss.py` → `jumpers.py` → `check_solderable.py` must all run to completion first. Link count is not linear in part count.

> **This replaced a two-layer version, and that version was unbuildable
> by you.** It had 110 pads whose only connection was on the far face, and
> every one of them sat under a component body — under the DIP switch,
> under U3 to U8, inside J2's own housing. Once the part is in the hole
> that copper is unreachable forever. Neither ERC nor DRC reports this,
> because both assume plated holes. `check_solderable.py` is the test that
> does; run it after any layout change.

## What it does without anything else attached

Probes → resistor ladder → one analog voltage → LM3914 → five thresholds.
A DIP switch picks the fill target, a CD4013 latches, and a Darlington
drives the pump contactor coil: **the pump runs only when the tank wants
water AND the well has water AND the excitation is alive.** No firmware,
no Pi, no network is involved in that path.

Five tank levels, not eight. Level resolution is 20% instead of 12.5%, and
in exchange the calibration window widens from 11% to 16.7% — which is
1/(N+1), the widest it can be. Hang the five probes non-uniformly
(5/20/45/70/95% of depth); probe height costs nothing.

The Raspberry Pi is optional. It reads levels over three wires and gives
you a dashboard; if it dies, the pump keeps working.

## Making it

Print at **100% scale, no fit-to-page**. The board fits one A4 sheet.

| File | What it is |
|---|---|
| `etch/1-COPPER-mirrored-iron-this-on.pdf` | the artwork — already mirrored for ironing |
| `etch/2-wire-links-map.pdf` | the 75 wire links, seen from the component side |
| `etch/3-component-placement.pdf` | what goes where |
| `etch/board2.drl` | hole sizes |

Build order:

1. Etch and drill.
2. **Fit the wire links first.** Several run under IC bodies and cannot be
   fitted afterwards. Work through `WIRE-LINKS.md` and tick them off.
3. Fit the low parts, then the ICs, then the connectors.
4. Solder everything from the copper side.

Copper is 0.8 mm track, 0.5 mm clearance, and stays 1.5 mm inside the cut
line — the router was fenced out of the margin so nothing gets nicked when
you saw the board out.

## Connectors — one row along the bottom edge

Each one sits directly under the circuit it feeds. That is not cosmetic:
on a single layer, a connector placed away from its own circuit turns
straight into hand-soldered wire. An earlier arrangement cost 3.7 m of it.

| Ref | Part | Ways | Purpose |
|-----|---|---|---|
| J1  | RJ45 | 8 | CAT5 to the control box: 5 V in and 3 data wires |
| J4  | 5.08 mm pluggable | 4 | pump contactor coil + watering valve |
| J11 | 3.5 mm pluggable | 4 | well: EXC common + W1..W3 |
| J2  | 3.5 mm pluggable | 6 | tank: EXC common + P1..P5 |

The two pitches are deliberate: a 5.08 mm pump plug will not fit a 3.5 mm
probe header, so they cannot be crossed.

### J1 must NOT be a magjack

Fit a **plain 8P8C receptacle** (Amphenol 54602 or equivalent). A magjack
has Ethernet transformers inside it. Nothing on this cable is Ethernet —
it carries DC and three logic lines — and **a transformer passes no DC**,
so the supply and all three signals would die inside the connector. The
footprint looks identical and the board routes and passes DRC either way.
Check the part description before you buy.

| Contact | Signal | Contact | Signal |
|---|---|---|---|
| 1, 2 | +5 V (doubled — 24 AWG drops volts) | 4 | SLOAD |
| 3, 7 | GND | 5 | SCLK |
| 8 | spare | 6 | SDATA |

Contacts 1+2 and 3+7 are joined on the board on purpose — two conductors
each for power and ground, halving the cable's resistance.

At the Pi end use an RJ45 breakout (~25 TL) and five jumpers to the GPIO.

## Probe cable — read this before wiring, it is not optional

**The EXC return must not share an unscreened multicore with the probe
cores.** Use screened cable with the screen earthed to the board's GND, or
run EXC as a separate conductor.

Cable capacitance between the EXC conductor and a probe conductor is a
current path that does not care whether the probe is wet. Ordinary
multicore is 60–120 pF/m, so 20 m puts ~1.2 nF beside each probe, and at
152 Hz that is 872 kΩ of reactance — the same order as a probe sitting in
rainwater. Simulated: with EXC run alongside the probe cores, **an empty
tank reads 1.2 V, which is four levels of water that is not there**, and
the pump never starts. With the same capacitance referenced to GND
instead, the empty tank reads 0.000 V at up to 2.4 nF.

This is the one failure mode that no amount of resistor value fixes, and
it is why the SSRC-04's 5–50 kΩ sensitivity ceiling is a feature rather
than a limitation: at a 50 kΩ threshold, cable reactance is 17× clear.
Reaching 300 kΩ rainwater is what forces the wiring rule.

## Commissioning

1. Power up with no probes connected. **EXC** (yellow) lights — if it is
   dark the oscillator is dead. That also now holds the pump off by
   itself, through D25, whatever SW2 is set to.
2. Fill the tank. **Wind RV1 up until the top LED goes out, then back off
   until it just lights again.**

   This is a self-checking test, and that is the whole reason exactly five
   LEDs are fitted for five probes. The point where the top LED
   extinguishes is exactly the top of the window in which probe *i* lights
   segment *i*; backing off from it can only move inward. Anywhere in the
   top 16.7% of that setting is correct, at every water resistance from
   1 kΩ to 300 kΩ.

   Wind too far up and the top LED stays dark — visibly wrong. Wind far
   too far down and the bar reads one level high; the bottom LED lighting
   with the tank near empty is the symptom.
3. Set the target level on **SW1**. The pump stops when the bar reaches
   that segment. **Every switch open now means "stop at the top probe"**
   rather than "never stop" — D26 ties the top segment in permanently.
4. Check the well: the three WELL LEDs should follow the well level, and
   **WELL** (green) means the interlock is satisfied.

## LED colours

Fitted, not driven — the gradient comes from which colour goes where.

- **Tank bar D10→D14** (bottom to top): 2 red, 1 yellow, 2 green
- **Well bar D22→D24**: red, yellow, green
- **Status**: D6 PUMP red, D7 EXC yellow

There is no PWR LED. D7 lighting already proves both that the rail is up
and that the oscillator on it is running, which is strictly more than a
power LED could say. D6 now hangs across the contactor coil, so it reports
the coil actually being energised rather than the latch's intention.

## Robustness — 1000 simulated installations

Water 1k (salty well) to 300k (rainwater in plastic), 3 to 5 probes
fitted, every ladder resistor and R19 drawn from ±5%, supply 4.75–5.25 V
**and drifting after commissioning**, 0–25 m of probe cable, RV1 wound by
hand off the visible top-LED edge.

**The pass criterion changed and is much stricter than the one that
produced the old 976/1000 figure.** It used to be that every probe
resolved to its own *distinct* segment. That is not what the control logic
assumes: `verify_logic.py` models `L[n] = (level < n)`, which needs probe
*i* to light segment *i* **exactly**. Distinctness passed happily on maps
like `[1,2,4,5,7,8,10,10]` — under which two DIP positions select the same
probe and one selects nothing at all. The two proofs were joined by an
assumption neither of them tested.

Scored against the criterion the logic actually needs:

| Board | Pass |
|---|---|
| the eight-probe ladder it replaced | **599 / 1000** |
| after the re-fit | **792 / 1000** |
| after RV1 made ratiometric | **809 / 1000** |

Of the remaining failures, roughly two thirds are **visible at
commissioning** — the top LED stays dark, or the bar lights on an empty
tank — because exactly N LEDs are fitted. The silent remainder is ~6%,
concentrated at 300 kΩ water with long cable, and is bottom-of-scale
compression: probes 1 and 2 landing on the same segment.

## Failure behaviour — verified over 576 states

Verified over **1536 states** — all 2^5 SW1 settings (not five of them),
every well state, filling and draining. The previous 576-state proof tested
one switch position per pass and so never tested the all-open state the DIP
switch ships in, which overfilled.

| Fault | What happens |
|---|---|
| Oscillator dies | both vessels read dry, **pump stops** |
| Oscillator dies, SW2-1 open | **pump still stops** — D25 clamps the enable |
| SW1 all positions open | **stops at the top probe** — D26 |
| Well goes dry | **pump stops**, valve unaffected |
| Pi dies / WiFi down | telemetry lost, **pump unaffected** |
| Tank probe shorted | reads full, pump stops, tank can run empty |
| **Tank probe open (corroded)** | reads empty, **pump keeps running — overfill** |
| **Well probe shorted** | reads wet, **pump can run dry** |

The last two are why an **independent overflow float switch in series with
the pump contactor is mandatory**, not optional. The board cannot detect a
probe that has failed open.

## The output is a signal, not a switch

U7, a ULN2003, sinks a **DC-rated contactor coil**. It must not switch the
138 V DC pump directly: DC arcs do not self-extinguish at a zero crossing, and any
PCB relay will weld its contacts. The contactor itself must also be
DC-rated — an AC contactor will weld too.

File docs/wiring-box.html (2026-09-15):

REISBOT · Pump Protection Box

# Wiring, three passes

Same backplate every time. Do one circuit, then the next — never all at once. Faded parts are not this pass. Terminals 1–5 are the box boundary: below them the wires leave through a gland.

PASS 1

## 143 V power — 8 wires

Breaker open. In at terminal 1, up the left, along the rail, through the contactor, back down to terminal 4. The return comes in at 3, through the shunt, to the − bus, out at 2.

PASS 2

## 24 V coil — 5 wires

The relay never touches 143 V. It switches the coil, and the coil switches the pump. Only the ⌒ hump is a crossing, not a joint.

PASS 3

## Sensing and control — 6 wires

Thin wire only; none of this carries pump current. The dashed pair is millivolts — twist it and keep it away from the pump cable.

Sense screws, not the fat bolts The shunt's small screws go to the PZEM. The M6 bolts go in the pump cable with ring lugs. Reversed, 50 A passes through a millivolt input and the meter is destroyed.

Amps reading zero? The pump-side small screw is SH+. Reversed, the meter shows 0.00 A while volts look perfect — it imitates a dead pump. Harmless; swap the two.

All three poles, every time The contactor is AC-rated. One gap will not break 143 V DC — it welds shut, and then the pump cannot be switched off at all.

## What each part looks like

Photos are examples of the type from Wikimedia Commons — they are not your exact parts, and I have left a card blank rather than show a lookalike where I could not verify one. On a 143 V DC build the wrong part is worse than no picture. The size and the identifying feature are the reliable checks; measure and read the label rather than matching the photo.

Pantec DC 16 A 550 V

example of the type

BREAKER

Pantec DC 16 A 550 V

2-pole · 36 mm wide

Must say DC and 550 V on the front. An AC breaker of the same shape will not break a DC arc.

no verified photo
identify by the description

FUSE

Hegel DC 1000 V holder

18 mm wide

Cartridge holder that hinges open. The body is marked 1000 V DC.

no verified photo
identify by the description

SPD

Type 2 DC surge arrester

36 mm wide

Two or three plug-in cartridges with a small window that turns red when the module is spent.

Schneider LP1K0901BD

example of the type

CONTACTOR

Schneider LP1K0901BD

45 × 58 × 57 mm

Coil terminals marked A1 and A2; poles marked 1–6. The BD suffix means a 24 V DC coil.

PA003-4 junction block ×3

example of the type

BUS

PA003-4 junction block ×3

on the DIN rail

A row of screw holes all connected internally. Both sides read 0 V apart — it joins wires, it does not measure.

no verified photo
identify by the description

SHUNT

50 A / 75 mV DC shunt

brass bar, ~80 mm

Two fat M6 bolts at the ends and two small screws in the middle. If it has only two terminals it is the wrong part. Must read 50 A, not 100 A.

no verified photo
identify by the description

PZEM-017

DC energy meter

black box, 4-pin header

Terminal block reading IN+ IN− SHUNT+ SHUNT− and a separate 2-pin RS485 A/B header. Comes with the USB cable.

no verified photo
identify by the description

HLK-10M24

143 V → 24 V supply

encapsulated brick, ~38 × 23 mm

Sealed black block, input and output pins at opposite ends, 24 V marked on the label.

no verified photo
identify by the description

LM2596

24 V → 5.1 V buck

~43 × 21 mm board

Small blue trimmer pot on top. Set it to 5.1 V before the Pi ever touches it.

no verified photo
identify by the description

RELAY

5 V relay module

1-channel board

Screw terminals marked COM NO NC and pins VCC GND IN. Use NO.

Raspberry Pi Zero W

example of the type

Pi

Raspberry Pi Zero W

65 × 30 mm

Two micro-USB sockets and a mini-HDMI. Photo is a Zero 2 W — same board outline, different centre chip.

no verified photo
identify by the description

LCD

20 × 4 character LCD

98 × 60 mm

I²C backpack soldered on the back with a blue contrast trimmer. Reads through the clear lid.

example of the type

GLAND

PG-16 cable gland ×2

PG-16 thread

One for the panel cable, one for the pump cable. Grips the sheath, not the conductors.

## Water level relays — the two SSRC-04s

Two SSRC-04 units, hacked to run on 12 V DC. Each uses three rods: B deepest (common reference), L low, U high. Both powered from the new 12 V rail. The well is the hard safety layer; the tank is the automation.

SSRC-04 terminal | WELL unit | TANK unit
A1 / A2 supply | 12 V + / − (HLK-20M12) | 12 V + / − (HLK-20M12)
B common rod | deepest, above the pump | bottom of tank
L low rod | min safe level | refill level
U high rod | recharge level | full level
C + NO output | in series with the contactor coil (hardware dry-run block) — and a PC817 opto across it → Pi pin 40 | C→GND pin 39, NO→Pi pin 38

Well = hardware safety, all modes C+NO physically in the contactor coil circuit. Dry well → coil can't energize → pump can't run, even if the Pi is dead. The PC817 opto just lets the Pi display it (pin 40), isolated from the 24 V coil.

Tank = automation, Auto only Straight to the Pi (pin 38). Full tank stops the pump in Auto; in Manual you may fill past it. The overflow float switch is the hardware backup here.

Screened probe cable Run the B/L/U rods on screened cable with the screen to GND, or cable capacitance reads as phantom water. Keep the EXC/common away from the probe cores.

No free photo exists for the PZEM-017, HLK-10M24, LM2596, relay board, shunt, SPD or LCD. The real pictures of the exact items are on the shop pages already linked in BUILD.md — open those on your phone when the parcels arrive.

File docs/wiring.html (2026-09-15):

Build reference · 138 V 1500 W DC submersible

# Solar pump protection — wiring

Three GSE-HC455 panels in series produce 150.9 V open-circuit at 25 °C, and more when cold. The pump's controller card dies above 150 V. This circuit keeps the contactor open until the array has settled into a safe band.

- 143 V DC array
- 24 V control
- 5 V logic
- Data

## 1 · What each part looks like

PZEM-017 kit

PZEM-017 kitThree pieces in the box: the black meter, the brass shunt, and the USB cable. The cable's white end has a screw terminal that wires to the meter's 4-pin header — no soldering.Screw terminal: IN+ · IN− · SHUNT+ · SHUNT−

20×4 LCD, blue

20×4 LCD, blueThe small board piggybacked on the back is the I²C adapter. The blue trimmer on it sets contrast — turn it if the screen lights up but shows nothing.GND · VCC · SDA · SCL

5 V relay module

5 V relay moduleThree screw terminals along the front edge, three pins on the side. The pins go to the Pi; the screws switch the 24 V coil circuit.Pins: VCC · GND · IN · Screws: NO · COM · NC

HLK-10M24

HLK-10M24Marked AC on the input pins, but the internal bridge rectifier accepts DC just as happily. Feed it 143 V from the array.AC · AC (in) → +Vo · −Vo (24 V out)

HLK-PM01

HLK-PM01Same family, 5 V output. Now spare — the LM2596 running off 24 V covers the Pi instead.AC · AC (in) → +Vo · −Vo (5 V out)

PA003-4 terminal

PA003-4 terminalWire enters the side, screw clamps from the top, pins solder into perfboard. Three of these form the 143 V bus.Rated 300 V · 15 A

The PZEM's USB cable ends in a screw terminal, so it wires to the 4-pin header directly. The RS485-to-USB conversion happens inside that white housing, which is why the cable has to reach a full-size USB-A port — and why an Arduino can't use it without a separate MAX485.

## 2 · Power path

Fig 1 — Array to pump. The shunt sits in the return leg, not the feed.

Break DC only with the breaker. A DC arc has no zero crossing to extinguish it. Never separate a live 143 V connection by hand.

Before touching any terminal: open the breaker, then confirm 0 V with a meter. Panels produce voltage in daylight regardless of what the pump is doing.

## 3 · Control wiring

Fig 2 — One 24 V supply feeds both the coil and, through the buck converter, all logic.

Set the LM2596 before it touches the Pi. These boards ship at anything from 1.2 V to 35 V. Feed it 24 V with the output disconnected, turn the trimmer until your meter reads 5.1 V, and only then wire it to pins 2 and 6.

## 4 · Pin connections

Raspberry Pi 4 — physical pins
Pi pin | Goes to | Carries
2 (5 V) | LM2596 out+ | Board power in
6 (GND) | LM2596 out− | Common ground
3 (SDA) | LCD SDA | I²C data
5 (SCL) | LCD SCL | I²C clock
11 (GPIO17) | Relay IN | Contactor command
USB-A | PZEM USB cable | Modbus RTU, 9600 8N2

PZEM-017 — screw terminal
Terminal | Goes to | Notes
IN+ | Terminal bus, positive | Also powers the module
IN− | Terminal bus, negative | —
SHUNT+ | Shunt small screw | Sense wire, order irrelevant
SHUNT− | Shunt small screw | Sense wire
micro USB | nothing | Only needed below 7 V

The shunt's two fat bolts carry the full pump current and belong in the negative line. The two small screws are the sense tap and go to the PZEM. Swapping those roles destroys the meter.

## 5 · Before you close the breaker

- Panels rewired to 3S1P — three in series, one string
- Contactor coil is on 24 V, never on the 143 V bus
- All three contactor poles chained in series, not paralleled
- Shunt in the negative return; fat bolts carry current, small screws sense
- LM2596 output measured at 5.1 V with the Pi disconnected
- SPD is DC-rated — an AC unit looks identical and fails dangerously here
- PZEM told it has the 50 A shunt: python3 test_hardware.py shunt
- Every 143 V screw torqued, no stray strands bridging terminals
- All grounds meet at one point — meter, buck converter, Pi
- Meter reads 0 V across the pump terminals with the breaker open

## 6 · What happens at sunrise

Time | Array | Controller
06:30 | 163 V | Panels cold, no load. Contactor open.
06:50 | 152 V | Warming. Still above the 138 V reset.
07:08 | 137 V | Inside the band — counting stable reads.
07:10 | 136 V | 30 consecutive. Contactor closes, pump starts.
07:11 | 126 V | Pump loading the array pulls it to Vmpp.
18:30 | 108 V | Light fading. Trips on undervoltage.

Every failure mode lands on pump off: lose the Pi, the script, the 24 V supply or the meter link, and the coil de-energizes. The pump only runs while the controller is alive and actively holding the relay closed.

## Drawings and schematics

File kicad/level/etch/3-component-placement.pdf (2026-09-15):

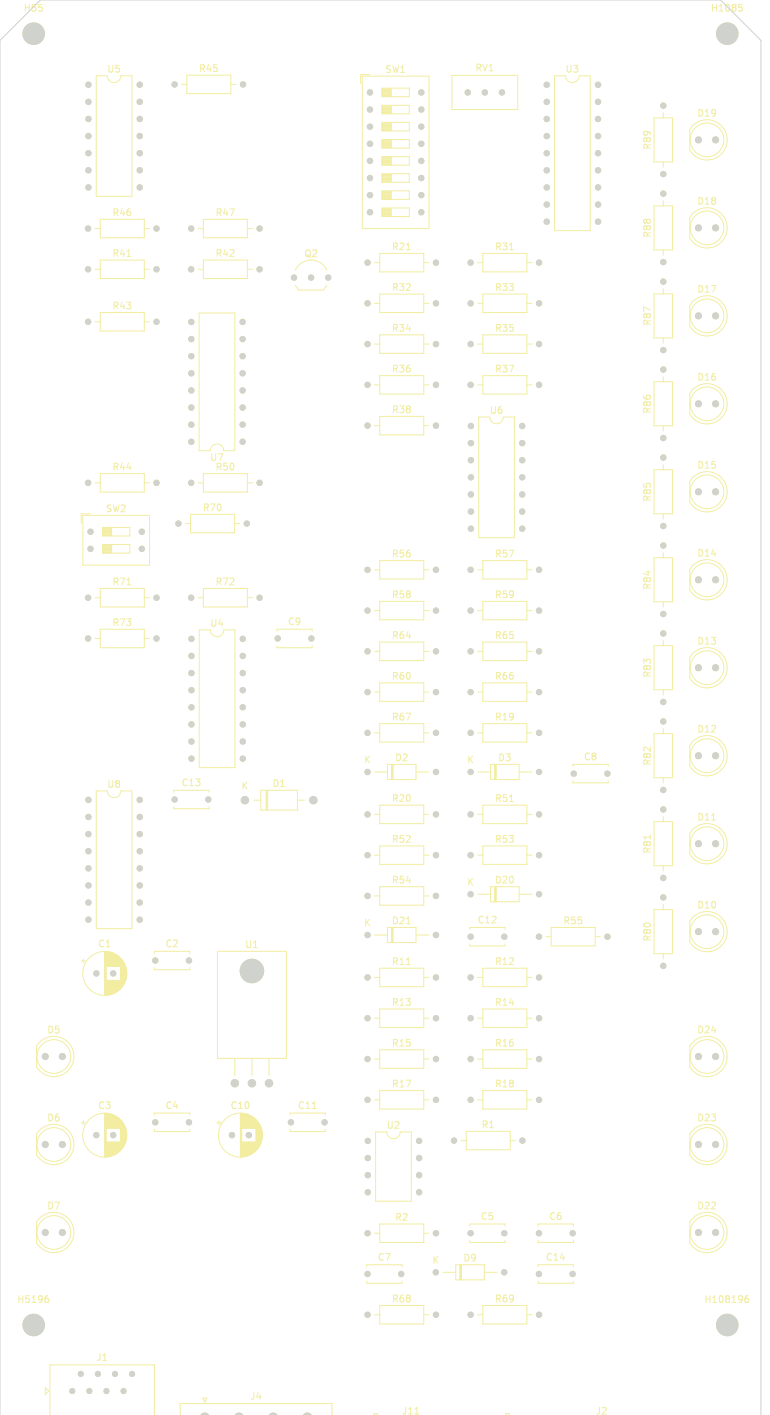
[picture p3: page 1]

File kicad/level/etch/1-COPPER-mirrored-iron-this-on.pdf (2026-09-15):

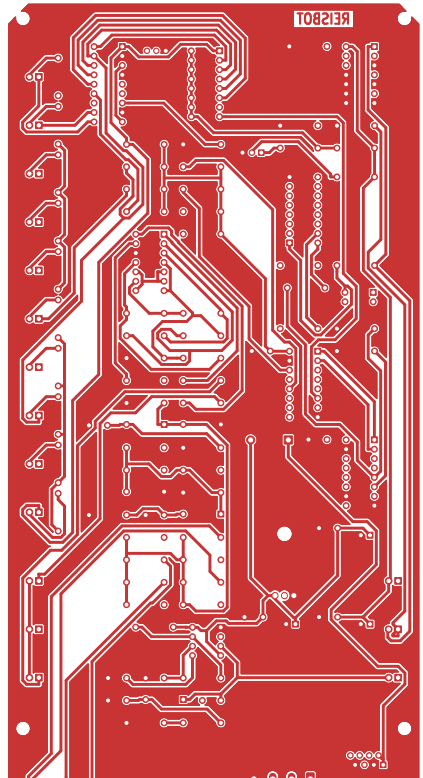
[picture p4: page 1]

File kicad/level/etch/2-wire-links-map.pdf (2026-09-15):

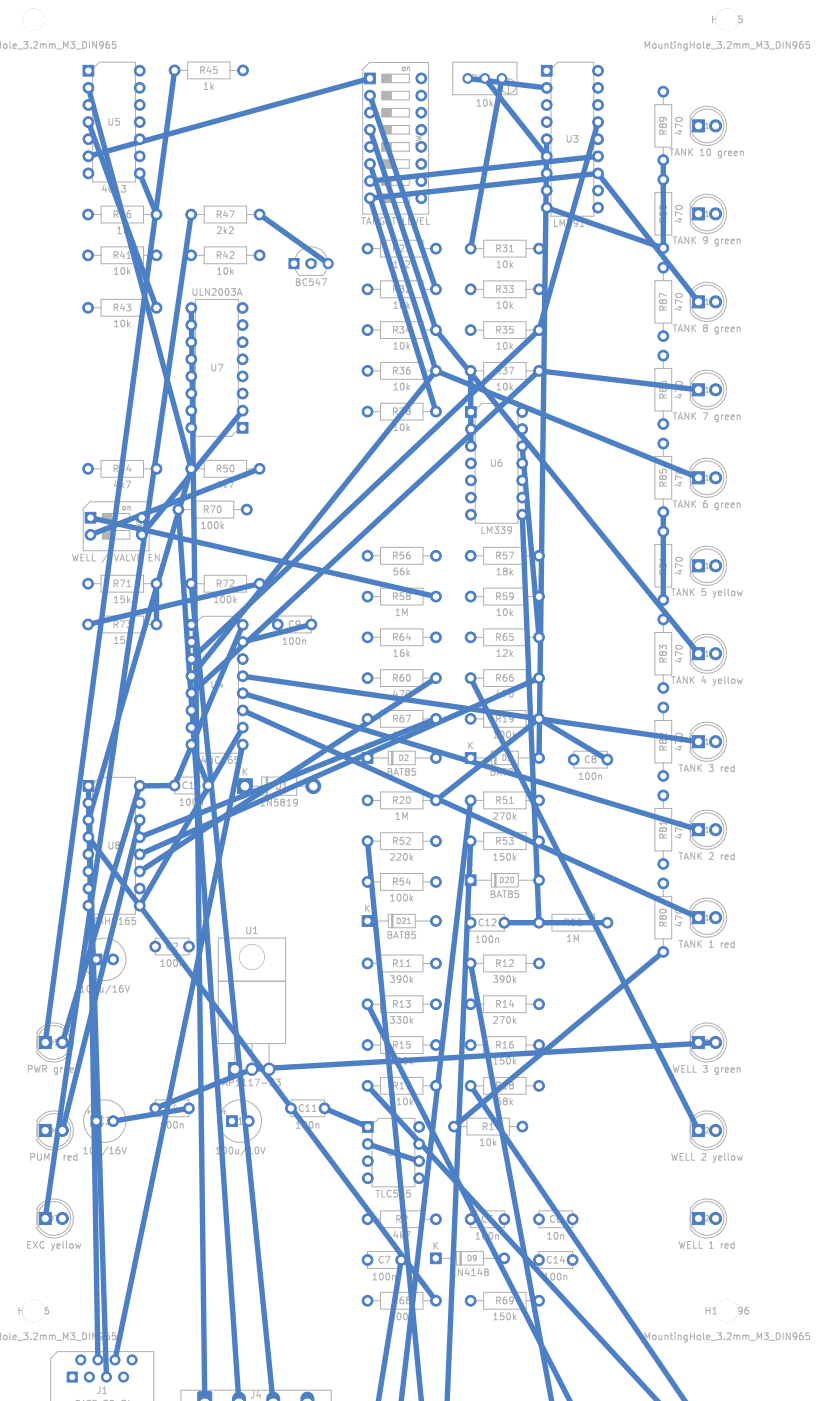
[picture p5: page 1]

TANK 10 green D19 TARGET LEVEL

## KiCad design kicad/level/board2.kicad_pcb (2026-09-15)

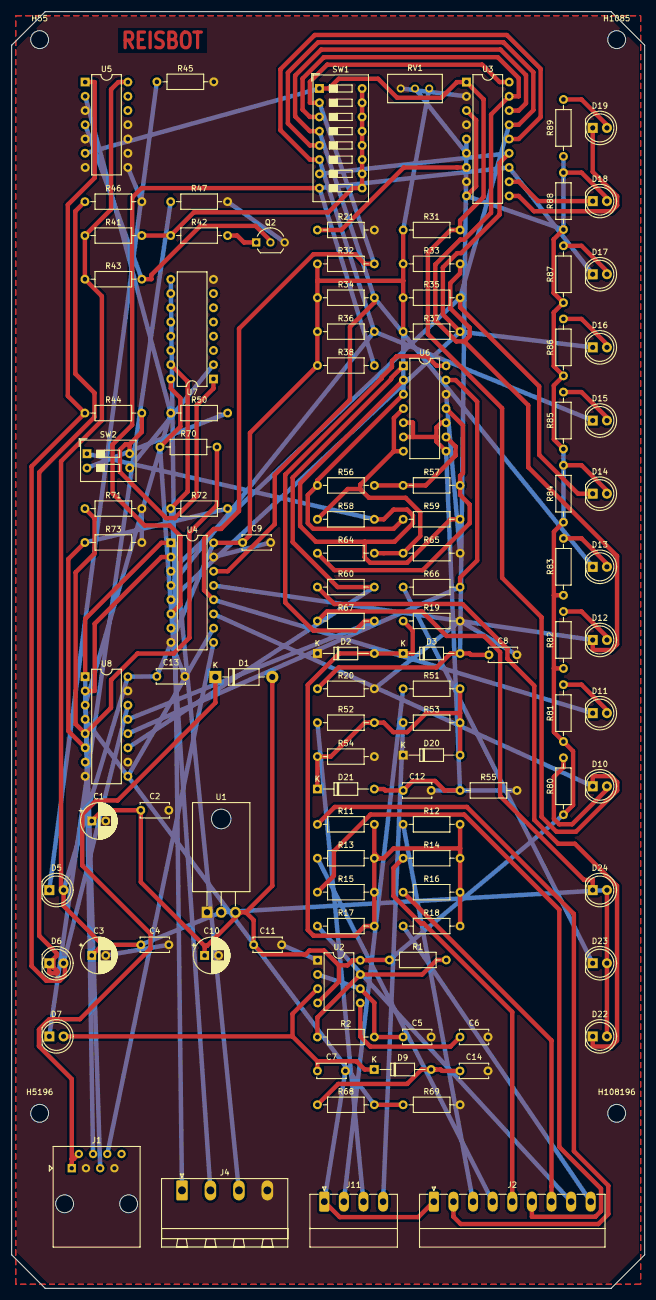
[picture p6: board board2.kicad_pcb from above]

Board: 2 copper layers, 113.0 x 227.9 mm, 115 parts (0 on the bottom side), 78 nets.

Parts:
C1: 100u/16V; CP_Radial_D6.3mm_P2.50mm
C2, C4, C5, C7, C8, C9, C11, C12, C13, C14: 100n; C_Disc_D5.0mm_W2.5mm_P5.00mm
C3: 10u/16V; CP_Radial_D6.3mm_P2.50mm
C6: 10n; C_Disc_D5.0mm_W2.5mm_P5.00mm
C10: 100u/10V; CP_Radial_D6.3mm_P2.50mm
D1: 1N5819; D_DO-41_SOD81_P10.16mm_Horizontal
D2, D3, D20, D21: BAT85; D_DO-35_SOD27_P10.16mm_Horizontal
D5: PWR green; LED_D5.0mm
D6: PUMP red; LED_D5.0mm
D7: EXC yellow; LED_D5.0mm
D9: 1N4148; D_DO-35_SOD27_P10.16mm_Horizontal
D10: TANK 1 red; LED_D5.0mm
D11: TANK 2 red; LED_D5.0mm
D12: TANK 3 red; LED_D5.0mm
D13: TANK 4 yellow; LED_D5.0mm
D14: TANK 5 yellow; LED_D5.0mm
D15: TANK 6 green; LED_D5.0mm
D16: TANK 7 green; LED_D5.0mm
D17: TANK 8 green; LED_D5.0mm
D18: TANK 9 green; LED_D5.0mm
D19: TANK 10 green; LED_D5.0mm
D22: WELL 1 red; LED_D5.0mm
D23: WELL 2 yellow; LED_D5.0mm
D24: WELL 3 green; LED_D5.0mm
H55, H1085, H5196, H108196: MountingHole_3.2mm_M3_DIN965
J1: CAT5 TO PI; RJ45_Amphenol_54602-x08_Horizontal
J2: PROBES; PhoenixContact_MC_1,5_9-G-3.5_1x09_P3.50mm_Horizontal
J4: PUMP / VALVE; PhoenixContact_MSTBA_2,5_4-G-5,08_1x04_P5.08mm_Horizontal
J11: WELL PROBES; PhoenixContact_MC_1,5_4-G-3.5_1x04_P3.50mm_Horizontal
Q2: BC547; TO-92_Inline_Wide
R1, R31, R32, R33, R34, R35, R36, R37, R38, R41, R42, R43, R59: 10k; R_Axial_DIN0207_L6.3mm_D2.5mm_P10.16mm_Horizontal
R2, R44, R50: 4k7; R_Axial_DIN0207_L6.3mm_D2.5mm_P10.16mm_Horizontal
R11, R12: 390k; R_Axial_DIN0207_L6.3mm_D2.5mm_P10.16mm_Horizontal
R13: 330k; R_Axial_DIN0207_L6.3mm_D2.5mm_P10.16mm_Horizontal
R14, R51: 270k; R_Axial_DIN0207_L6.3mm_D2.5mm_P10.16mm_Horizontal
R15: 200k; R_Axial_DIN0207_L6.3mm_D2.5mm_P10.16mm_Horizontal
R16, R53, R69: 150k; R_Axial_DIN0207_L6.3mm_D2.5mm_P10.16mm_Horizontal
R17: 110k; R_Axial_DIN0207_L6.3mm_D2.5mm_P10.16mm_Horizontal
R18: 68k; R_Axial_DIN0207_L6.3mm_D2.5mm_P10.16mm_Horizontal
R19, R54, R68, R70, R72: 100k; R_Axial_DIN0207_L6.3mm_D2.5mm_P10.16mm_Horizontal
R20, R55, R58: 1M; R_Axial_DIN0207_L6.3mm_D2.5mm_P10.16mm_Horizontal
R21: 1k2; R_Axial_DIN0207_L6.3mm_D2.5mm_P10.16mm_Horizontal
R45, R46: 1k; R_Axial_DIN0207_L6.3mm_D2.5mm_P10.16mm_Horizontal
R47: 2k2; R_Axial_DIN0207_L6.3mm_D2.5mm_P10.16mm_Horizontal
R52: 220k; R_Axial_DIN0207_L6.3mm_D2.5mm_P10.16mm_Horizontal
R56: 56k; R_Axial_DIN0207_L6.3mm_D2.5mm_P10.16mm_Horizontal
R57: 18k; R_Axial_DIN0207_L6.3mm_D2.5mm_P10.16mm_Horizontal
R60, R66, R67, R80, R81, R82, R83, R84, R85, R86, R87, R88, R89: 470; R_Axial_DIN0207_L6.3mm_D2.5mm_P10.16mm_Horizontal
R64: 16k; R_Axial_DIN0207_L6.3mm_D2.5mm_P10.16mm_Horizontal
R65: 12k; R_Axial_DIN0207_L6.3mm_D2.5mm_P10.16mm_Horizontal
R71, R73: 15k; R_Axial_DIN0207_L6.3mm_D2.5mm_P10.16mm_Horizontal
RV1: 10k; Potentiometer_Bourns_3296W_Vertical
SW1: TARGET LEVEL; SW_DIP_SPSTx08_Slide_9.78x22.5mm_W7.62mm_P2.54mm
SW2: WELL / VALVE EN; SW_DIP_SPSTx02_Slide_9.78x7.26mm_W7.62mm_P2.54mm
U1: AP1117-33; TO-220-3_Horizontal_TabDown
U2: TLC555; DIP-8_W7.62mm
U3: LM3914; DIP-18_W7.62mm
U4, U8: 74HC165; DIP-16_W7.62mm
U5: 4013; DIP-14_W7.62mm
U6: LM339; DIP-14_W7.62mm
U7: ULN2003A; DIP-16_W7.62mm

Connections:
+3V3: C3.1, C4.1, C9.1, C13.1, D5.2, D22.2, D23.2, D24.2, R31.1, R32.1, R33.1, R34.1, R35.1, R36.1, R37.1, R38.1, R41.1, R43.1, R56.1, R59.1, RV1.1, U1.2, U4.16, U5.14, U6.3, U8.16
+5V: C1.1, C2.1, C10.1, C11.1, D1.2, R1.1, R80.1, R81.1, R82.1, R83.1, R84.1, R85.1, R86.1, R87.1, R88.1, R89.1, U1.3, U2.4, U2.8, U3.3, U3.9
COIL_V: J4.1, U7.9
DET: C8.1, D3.2, R20.1, U3.5
EXC: C7.2, J2.1, J11.1
EXC_OK: R68.2, R69.1, U8.4
EXC_RAW: C14.1, D9.2, R68.1
GND: C1.2, C2.2, C3.2, C4.2, C5.2, C6.2, C8.2, C9.2, C10.2, C11.2, C12.2, C13.2, C14.2, D2.1, D20.1, J1.3, J1.7, J4.4, Q2.3, R19.2, R20.2, R21.2, R45.2, R46.2, R47.2, R54.2, R55.2, R65.2, R69.2, R71.2, R73.2, RV1.3, U1.1, U2.1, U3.2, U3.4, U3.8, U4.8, U4.15, U5.3, U5.5, U5.7, U5.8, U5.9, U5.10, U5.11, U6.12, U7.8, U8.8, U8.10, U8.15
L1: D10.1, R31.2, SW1.1, U3.1, U4.11, U5.6
L2: D11.1, R32.2, SW1.2, U3.18, U4.12
L3: D12.1, R33.2, SW1.3, U3.17, U4.13
L4: D13.1, R34.2, SW1.4, U3.16, U4.14
L5: D14.1, R35.2, SW1.5, U3.15, U4.3
L6: D15.1, R36.2, SW1.6, U3.14, U4.4
L7: D16.1, R37.2, SW1.7, U3.13, U4.5
L8: D17.1, R38.2, SW1.8, U3.12, U4.6
L9: D18.1, U3.11
L10: D19.1, U3.10
LA1: D10.2, R80.2
LA2: D11.2, R81.2
LA3: D12.2, R82.2
LA4: D13.2, R83.2
LA5: D14.2, R84.2
LA6: D15.2, R85.2
LA7: D16.2, R86.2
LA8: D17.2, R87.2
LA9: D18.2, R88.2
LA10: D19.2, R89.2
LADDER: D2.2, D3.1, R11.2, R12.2, R13.2, R14.2, R15.2, R16.2, R17.2, R18.2, R19.1
LEDW0: D22.1, R60.1
LEDW1: D23.1, R66.1
LEDW2: D24.1, R67.1
LED_EXC: D7.1, R47.1
LED_PMP: D6.1, R46.1
LED_PWR: D5.1, R45.1
OSC_C: C6.1, U2.5
OSC_D: R1.2, R2.1, U2.7
OSC_OUT: C7.1, D7.2, D9.1, U2.3
OSC_T: C5.1, R2.2, U2.2, U2.6
P1: J2.2, R11.1
P2: J2.3, R12.1
P3: J2.4, R13.1
P4: J2.5, R14.1
P5: J2.6, R15.1
P6: J2.7, R16.1
P7: J2.8, R17.1
P8: J2.9, R18.1
PUMP: D6.2, R44.1, U5.1, U8.14
PUMP_EN: R44.2, SW2.4, U7.1
PUMP_N: R50.1, U5.2, U8.3
PUMP_OUT: J4.2, R70.1, U7.16
PUMP_SNS: R70.2, R71.1, U8.5
Q2B: Q2.1, R42.2
REF: R21.1, U3.7
RHI_SET: RV1.2, U3.6
SCLK: J1.5, U4.2, U8.2
SDATA: J1.6, U4.9
SLOAD: J1.4, U4.1, U8.1
TARGET: R41.2, R42.1, SW1.9, SW1.10, SW1.11, SW1.12, SW1.13, SW1.14, SW1.15, SW1.16
TGT_HI: Q2.2, R43.2, U5.4
U8Q7: U4.10, U8.9
VIN: D1.1, J1.1, J1.2
VLV_EN: SW2.3, U7.2
VLV_GATE: R50.2, SW2.2
VLV_OUT: J4.3, R72.1, U7.15
VLV_SNS: R72.2, R73.1, U8.6
W1: J11.2, R51.1
W2: J11.3, R52.1
W3: J11.4, R53.1
WDET: C12.1, D21.2, R55.1, U6.5, U6.6, U6.8, U6.10
WELL1: R60.2, U6.1, U8.11
WELL2: R66.2, U6.13, U8.12
WELL3: R67.2, U6.14, U8.13
WELL_OK: R58.2, R59.2, SW2.1, U6.2
WLADDER: D20.2, D21.1, R51.2, R52.2, R53.2, R54.1
WREF1: R58.1, R64.2, R65.1, U6.4, U6.7
WREF2: R57.2, R64.1, U6.11
WREF3: R56.2, R57.1, U6.9

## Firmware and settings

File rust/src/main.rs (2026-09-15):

//! Solar pump protection controller.
//!
//! Holds the contactor open unless the array voltage is inside a safe band,
//! so the pump's controller card never sees the open-circuit voltage the
//! panels produce before any current is drawn - which is what destroyed the
//! previous pump on a cold morning.
//!
//! Everything fails toward "pump off". The contactor is normally open and
//! only closes while this process actively holds the relay. Losing power,
//! the process, the meter, or the relay all drop the pump.

mod display;
mod failsafe;
mod meter;
mod panel;
mod settings;
mod sound;
mod state;
mod watchdog;
mod web;

use std::path::PathBuf;
use std::sync::atomic::{AtomicBool, AtomicU64, Ordering};
use std::sync::mpsc::SyncSender;
use std::sync::{Arc, Mutex, OnceLock};
use std::time::{Duration, SystemTime, UNIX_EPOCH};

use meter::Meter;
use panel::Panel;
use settings::Settings;
use state::{Command, Machine, Mode, State};

const DATA_DIR: &str = "/var/lib/pump-protection";

/// How often the meter is read and the protection re-evaluated.
const POLL: Duration = Duration::from_millis(500);
/// Buttons are scanned far more often than the meter, so a press acts
/// immediately instead of waiting up to half a second for the next poll.
const BUTTON_SCAN: Duration = Duration::from_millis(20);

// GPIO assignments, BCM numbering. None disables that control, so the
// controller runs with any subset of the panel wired.
const RELAY_PIN: u8 = 17;
const PANEL: panel::Pins = panel::Pins {
    profile_jumper: Some(12), // physical 32 - ground it for BENCH testing
    // Swapped to match how the switch is actually wired: the pin that ends
    // up grounded in the left position is 6, not 5.
    switch_left: Some(6),   // physical 31 - grounded = OFF
    switch_right: Some(5),  // physical 29 - grounded = AUTO
    start: Some(16),        // physical 36 - green button
    stop: Some(13),         // physical 33 - red button
    led_green: Some(19),    // physical 35
    led_red: Some(26),      // physical 37
    // Hacked SSRC-04 level relays. Isolated dry contact: wire C to GND and
    // NO (or NC, chosen for fail-safe) to the pin. Both free on the header.
    tank_relay: Some(20),   // physical 38
    well_relay: Some(21),   // physical 40
};

pub fn now_secs() -> u64 {
    SystemTime::now()
        .duration_since(UNIX_EPOCH)
        .map(|d| d.as_secs())
        .unwrap_or(0)
}

pub fn now_string() -> String {
    chrono::Local::now().format("%Y-%m-%d %H:%M:%S").to_string()
}

fn today() -> String {
    chrono::Local::now().format("%Y-%m-%d").to_string()
}

fn data(name: &str) -> PathBuf {
    PathBuf::from(DATA_DIR).join(name)
}

/// Mode survives restart - a power cut must not silently re-arm a pump
/// someone deliberately switched off.
fn load_mode() -> Mode {
    match std::fs::read_to_string(data("mode")) {
        Ok(s) => match s.trim() {
            "auto" => Mode::Auto,
            "off" => Mode::Off,
            _ => Mode::Manual,
        },
        // First run: Manual is the cautious default. The operator opts in
        // to autonomy rather than discovering it.
        Err(_) => Mode::Manual,
    }
}

// ---- persistence writer thread -------------------------------------------
// A dying SD card can make a file write BLOCK for seconds (the kernel retries
// bad blocks). Doing that in the control loop would freeze the protection with
// the contactor possibly CLOSED - the field's LCD freeze was this same class of
// bug (a blocking peripheral op in the hot loop). So all disk persistence goes
// through a bounded channel to a writer thread; the loop only ever does a
// non-blocking try_send and DROPS the job if the card cannot keep up. Live
// protection never waits on the disk. Persistence is best-effort - and a lost
// dry-run lockout is still caught by the well sensor on the next run.
enum Job {
    Mode(&'static str),
    Lockout(u64, u32),
    History(String),
    Heartbeat(u64),
}

static PERSIST: OnceLock<SyncSender<Job>> = OnceLock::new();

fn start_persister() {
    let (tx, rx) = std::sync::mpsc::sync_channel::<Job>(128);
    let _ = PERSIST.set(tx);
    std::thread::spawn(move || {
        // A blocking write here stalls ONLY this thread, never the control loop.
        for job in rx {
            match job {
                Job::Mode(s) => {
                    let _ = std::fs::write(data("mode"), s);
                }
                Job::Lockout(until, strikes) => {
                    let _ = std::fs::write(data("lockout"), format!("{until},{strikes}"));
                }
                Job::History(line) => {
                    use std::io::Write;
                    let path = data("history.csv");
                    // Rotate at a cap so months of 5s samples can never fill the
                    // card, and /history.csv can never read a huge file into the
                    // Pi Zero's 512MB RAM. One old file is kept: bounded to ~2x.
                    const HISTORY_CAP: u64 = 4 * 1024 * 1024;
                    if std::fs::metadata(&path).map(|m| m.len()).unwrap_or(0) >= HISTORY_CAP {
                        let _ = std::fs::rename(&path, data("history.csv.old"));
                    }
                    let new = !path.exists();
                    if let Ok(mut f) = std::fs::OpenOptions::new().create(true).append(true).open(&path) {
                        if new {
                            let _ = f.write_all(b"timestamp,volts,amps,watts,kwh,state,mode,dry_flag\n");
                        }
                        let _ = f.write_all(line.as_bytes());
                    }
                }
                Job::Heartbeat(t) => {
                    let _ = std::fs::write(data("heartbeat"), t.to_string());
                }
            }
        }
    });
}

fn persist(job: Job) {
    if let Some(tx) = PERSIST.get() {
        // Non-blocking: drop the job if the writer is backed up on a slow card.
        let _ = tx.try_send(job);
    }
}

fn save_mode(m: Mode) {
    persist(Job::Mode(match m {
        Mode::Auto => "auto",
        Mode::Manual => "manual",
        Mode::Off => "off",
    }));
}

/// Dry-run lockouts persist too, so a restart cannot be used to bypass the
/// rest a drawn-down well needs.
fn load_lockout() -> (u64, u32) {
    std::fs::read_to_string(data("lockout"))
        .ok()
        .and_then(|s| {
            let mut it = s.trim().split(',');
            Some((it.next()?.parse().ok()?, it.next()?.parse().ok()?))
        })
        .unwrap_or((0, 0))
}

fn save_lockout(until: u64, strikes: u32) {
    persist(Job::Lockout(until, strikes));
}

fn local_ip() -> Option<String> {
    // Client mode: ask the kernel which source address it would use to reach a
    // public address. Nothing is actually sent.
    if let Ok(sock) = std::net::UdpSocket::bind("0.0.0.0:0") {
        if sock.connect("192.0.2.1:1").is_ok() {
            // TEST-NET-1, never routed
            if let Ok(addr) = sock.local_addr() {
                return Some(addr.ip().to_string());
            }
        }
    }
    // AP / hotspot mode has NO default route, so the connect above fails with
    // "network unreachable" - read the first real IPv4 straight off the
    // interfaces instead. This is what puts the 192.168.4.1 hotspot address on
    // the LCD, the case the operator most needs to see.
    first_iface_ipv4()
}

/// First non-loopback, non-link-local IPv4 assigned to any interface, via
/// getifaddrs. Covers the AP case (wlan0 = 192.168.4.1) where route lookup fails.
fn first_iface_ipv4() -> Option<String> {
    unsafe {
        let mut ifap: *mut libc::ifaddrs = std::ptr::null_mut();
        if libc::getifaddrs(&mut ifap) != 0 {
            return None;
        }
        let mut cur = ifap;
        let mut found = None;
        while !cur.is_null() {
            let ifa = &*cur;
            if !ifa.ifa_addr.is_null() && (*ifa.ifa_addr).sa_family as i32 == libc::AF_INET {
                let sin = ifa.ifa_addr as *const libc::sockaddr_in;
                // s_addr is network byte order; its in-memory bytes are the
                // octets in order on any host.
                let o = (*sin).sin_addr.s_addr.to_ne_bytes();
                let loopback = o[0] == 127;
                let link_local = o[0] == 169 && o[1] == 254;
                if !loopback && !link_local {
                    found = Some(format!("{}.{}.{}.{}", o[0], o[1], o[2], o[3]));
                    break;
                }
            }
            cur = ifa.ifa_next;
        }
        libc::freeifaddrs(ifap);
        found
    }
}

/// Find the meter's serial port, resolved fresh every time it is opened.
///
/// A USB serial adapter does NOT come back on the same path. When the CH341
/// on this box glitched and re-enumerated, the kernel attached it to
/// /dev/ttyUSB1 while pumpd went on reopening /dev/ttyUSB0 every ten seconds
/// for ever. The meter is the only source of voltage truth, so that left the
/// guard permanently blind: it failed safe - Fault, contactor open - but it
/// could never recover, and no unattended box comes back from that without a
/// person walking to it and restarting the service.
///
/// /dev/serial/by-id is the stable name. It is built from the adapter's own
/// vendor and serial identifiers rather than from the order things were
/// plugged in, so it follows the device across a re-enumeration.
fn meter_port(pinned: Option<&str>) -> Option<String> {
    // An explicitly pinned PZEM_PORT wins while it exists. If it has
    // vanished, fall through and discover rather than fail for ever - a
    // pinned path that no longer resolves is exactly the situation that
    // stranded the box.
    if let Some(p) = pinned {
        if std::path::Path::new(p).exists() {
            return Some(p.to_string());
        }
        eprintln!("PZEM_PORT {p} is not present, looking for the meter");
    }

    let mut by_id: Vec<PathBuf> = std::fs::read_dir("/dev/serial/by-id")
        .into_iter()
        .flatten()
        .flatten()
        .map(|e| e.path())
        .collect();
    by_id.sort();
    // 1a86 is the CH340/CH341 bridge the PZEM ships behind. Prefer it when
    // several adapters are present, but take any serial device over none.
    if let Some(p) = by_id
        .iter()
        .find(|p| p.to_string_lossy().contains("1a86"))
        .or_else(|| by_id.first())
    {
        return Some(p.to_string_lossy().into_owned());
    }

    // Last resort, for a kernel with no by-id links: the lowest ttyUSB.
    let mut tty: Vec<PathBuf> = std::fs::read_dir("/dev")
        .into_iter()
        .flatten()
        .flatten()
        .map(|e| e.path())
        .filter(|p| {
            p.file_name()
                .and_then(|n| n.to_str())
                .is_some_and(|n| n.starts_with("ttyUSB"))
        })
        .collect();
    tty.sort();
    tty.first().map(|p| p.to_string_lossy().into_owned())
}

fn append_history(r: &meter::Reading, st: State, mode: Mode, dry_flag: bool) {
    // Format here (cheap, no I/O), hand the line to the writer thread.
    let line = format!(
        "{},{:.1},{:.2},{:.0},{:.3},{},{},{}\n",
        now_string(),
        r.volts,
        r.amps,
        r.watts,
        r.watt_hours / 1000.0,
        format!("{st:?}").to_lowercase(),
        mode.label().to_lowercase(),
        if dry_flag { 1 } else { 0 }
    );
    persist(Job::History(line));
}

struct Relay {
    pin: Option<rppal::gpio::OutputPin>,
}

impl Relay {
    fn new(bcm: u8) -> Self {
        match rppal::gpio::Gpio::new().and_then(|g| g.get(bcm)) {
            Ok(p) => {
                let mut pin = p.into_output();
                pin.set_low(); // open on startup, always
                Relay { pin: Some(pin) }
            }
            Err(e) => {
                eprintln!("relay gpio unavailable: {e}");
                Relay { pin: None }
            }
        }
    }

    fn set(&mut self, closed: bool) {
        if let Some(p) = &mut self.pin {
            if closed {
                p.set_high()
            } else {
                p.set_low()
            }
        }
    }
}

/// Green button: start, or clear a fault and arm if one is standing.
///
/// Shared by the fast button scan and the main loop so a press is handled
/// identically wherever it is noticed.
/// Green button: start, or clear a fault and arm if one is standing.
///
/// Returns a short message when the request was refused, for the display to
/// latch. Nothing sleeps here - this runs inside the protection loop, and
/// blocking it would stop the overvoltage check for as long as the message
/// was on screen.
fn handle_start(machine: &mut Machine, settings: &Settings) -> Option<String> {
    let now = now_secs();

    if matches!(machine.state, State::Tripped | State::Fault | State::Lockout) {
        let _ = machine.command(Command::ClearLockout, now, settings);
        let _ = machine.command(Command::Reset, now, settings);
        save_lockout(0, 0);
        println!("green - cleared fault, arming");
        return None;
    }

    match machine.command(Command::Start, now, settings) {
        Ok(()) => None,
        Err(refusal) => {
            let msg = refusal.message();
            println!("refused: {msg}");
            Some(msg)
        }
    }
}

/// What the LED should show, including why a start is being refused.
///
/// Waiting carries no reason of its own, so the band is checked here and
/// the same two patterns that mean "tripped on volts" are reused for
/// "will not start on volts". One vocabulary, whichever side it happens on.
fn led_want(machine: &state::Machine, s: &settings::Settings) -> panel::Led {
    let blocked = if machine.state == State::Waiting {
        machine.last.and_then(|r| {
            if r.volts > s.v_high_reset {
                Some(state::TripReason::OverVoltage)
            } else if r.volts < s.v_low_reset {
                Some(state::TripReason::UnderVoltage)
            } else {
                None
            }
        })
    } else {
        None
    };
    panel::led_for(machine.state, machine.reason, blocked)
}

/// Turn a panel event into a machine command, via whatever screen is up.
///
/// Returns true if anything was acted on, so the caller knows to re-evaluate
/// and repaint immediately rather than waiting for the next poll.
fn handle_input(
    input: panel::Input,
    machine: &mut Machine,
    settings: &Settings,
    refusal: &mut Option<String>,
    refusal_until: &mut u64,
) -> bool {
    let now = now_secs();
    let mut acted = false;

    // The handle is the mode. Nothing else can set it, so it can never
    // disagree with what the panel shows.
    if let Some(m) = input.mode {
        println!("mode switch moved to {}", m.label());
        let _ = machine.command(Command::SetMode(m), now, settings);
        save_mode(m);
        acted = true;
        // The far-left OFF position is a hardware "stop everything": open the
        // pump (SetMode(Off) above did) and, past the boot grace, power the Pi
        // down cleanly. The main loop performs it (it holds the relay + syncs).
        let uptime = BOOT_AT.get().map(|b| b.elapsed()).unwrap_or_default();
        if should_power_off(input.mode, uptime) {
            POWER_OFF_REQUESTED.store(true, Ordering::SeqCst);
        }
    }

    // Red first, and unconditionally. If both arrive in the same drain,
    // stopping is the one that must win.
    if input.stop.is_some() {
        let _ = machine.command(Command::Stop, now, settings);
        acted = true;
    }

    if input.start.is_some() {
        if let Some(msg) = handle_start(machine, settings) {
            *refusal = Some(msg);
            *refusal_until = now + 4;
        }
        acted = true;
    }

    acted
}
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

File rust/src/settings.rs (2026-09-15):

//! Operator-adjustable settings, persisted as JSON.
//!
//! Validation runs before anything is written, so a bad value from the
//! dashboard is rejected with an explanation rather than saved and acted on.
//! A corrupt file falls back to defaults - the pump keeps its protection
//! even if the disk is damaged.

use serde::{Deserialize, Serialize};
use std::path::Path;

/// Which set of thresholds is in force.
///
/// The bench profile lets the whole system be exercised from a small DC
/// supply. The pump profile carries the real numbers. Keeping both in the
/// binary means commissioning is a single flag, not eight values retyped
/// correctly in a shed.
#[derive(Debug, Clone, Copy, PartialEq, Eq, Serialize, Deserialize)]
#[serde(rename_all = "lowercase")]
pub enum Profile {
    /// Low voltage bench supply, 10-17V working range.
    Bench,
    /// The real array: 3x GSE-HC455 in series feeding a 138V 1500W pump.
    Pump,
}

impl Profile {
    pub fn label(self) -> &'static str {
        match self {
            Profile::Bench => "BENCH",
            Profile::Pump => "PUMP",
        }
    }

    /// Thresholds for this profile. Everything voltage- or current-related
    /// comes from here; timing and dry-run tuning carry across.
    pub fn thresholds(self) -> Thresholds {
        match self {
            Profile::Bench => Thresholds {
                v_high_trip: 18.0,
                v_low_trip: 9.0,
                v_high_reset: 17.0,
                v_low_reset: 10.0,
                i_max: 5.0,
                dry_amps: 0.5,
                dry_volts: 16.0,
            },
            // The pump's controller card is destroyed above 150V, and the
            // array reaches 150.9V open-circuit at 25C - higher when cold.
            // It self-protects below 110V, so we stop just above that.
            // Straight off the pump's own listing: "Ürün 110V-150V arasında
            // çalışmaktadır", below 110V its card self-protects, above 150V
            // that card is damaged. So 110-150 is the hard envelope and
            // everything here is derived from it.
            //
            // v_high_reset was 138 and that was a real flaw, found in the
            // field. The array sits near 150.9V open circuit, so after any
            // trip it could not fall back under 138V until evening - one trip
            // cost a whole day of pumping. 142 is still 8V under the damage
            // point, and the pump only sees it for the instant before 11A
            // drags the array down to its operating point.
            //
            // The low trip stays 2V above the pump's own 110V cutout on
            // purpose: this controller should act first, so a stop is our
            // decision and is logged, rather than the pump quietly
            // protecting itself with nobody knowing why it stopped.
            Profile::Pump => Thresholds {
                // v_low_trip 95, not 112: 1417 minutes of field data show the
                // pump operates at a median 109V down to 100.4V under load,
                // and its own protection does not engage even at 100V. 112
                // was tripping it mid-run - start at 137V, sag under load,
                // undervoltage trip, array recovers to 137V, restart: exactly
                // the start/stop cycling that wears a motor. 95 sits below the
                // real operating floor with margin. The pump reads a little
                // less than the box at the far end of the cable.
                //
                // dry_amps 3.0 / dry_volts 125: the boundary between the wet
                // operating region (median 109V, 3.5-6A) and a dry pump (high
                // volts, low amps). A loaded pump is always well under 125V;
                // only high-volts AND low-amps together read as dry.
                v_high_trip: 145.0,
                v_low_trip: 95.0,
                v_high_reset: 142.0,
                v_low_reset: 110.0,
                i_max: 13.0,
                dry_amps: 3.0,
                dry_volts: 125.0,
            },
        }
    }
}

#[derive(Debug, Clone, Copy)]
pub struct Thresholds {
    pub v_high_trip: f32,
    pub v_low_trip: f32,
    pub v_high_reset: f32,
    pub v_low_reset: f32,
    pub i_max: f32,
    pub dry_amps: f32,
    pub dry_volts: f32,
}
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

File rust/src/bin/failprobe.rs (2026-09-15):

//! End-to-end proof for the panic failsafe (NOT shipped in any image).
//!
//! Exercises the REAL `failsafe::arm` hook against real GPIO registers, so we
//! can observe that a genuine panic actually drives the relay pin low.
//!
//! Run in the QEMU Void box (which provides /dev/mem GPIO), one mode per
//! invocation; the pin level persists in hardware between processes:
//!   failprobe sethigh   -> drive GPIO17 high, exit WITHOUT resetting it
//!   failprobe read      -> print the live level of GPIO17
//!   failprobe armpanic  -> drive GPIO17 high, arm the failsafe, then panic
//! Expected: after `sethigh` a `read` sees 1 (high persists across processes);
//! after `armpanic` a `read` sees 0 (the panic hook opened the contactor).

#[path = "../failsafe.rs"]
mod failsafe;

fn main() {
    let mode = std::env::args().nth(1).unwrap_or_default();
    let pin: u8 = 17;
    let base = match failsafe::map_for_probe() {
        Some(b) => b,
        None => {
            eprintln!("failprobe: cannot map GPIO (need /dev/gpiomem or /dev/mem as root)");
            std::process::exit(3);
        }
    };

    match mode.as_str() {
        "sethigh" => {
            unsafe { failsafe::set_output_high(base, pin) };
            println!("SETHIGH level={}", unsafe { failsafe::read_level(base, pin) });
            // Leave the pin driven high: exit without running any Drop, so the
            // next process can confirm an output level persists in hardware.
            unsafe { libc::_exit(0) };
        }
        "read" => {
            println!("PIN{}={}", pin, unsafe { failsafe::read_level(base, pin) });
        }
        "armpanic" => {
            unsafe { failsafe::set_output_high(base, pin) };
            println!("ARMPANIC before={}", unsafe { failsafe::read_level(base, pin) });
            failsafe::arm(pin); // the production hook under test
            println!("ARMPANIC panicking now");
            panic!("failprobe induced panic - the hook must open the relay");
        }
        "softkill" => {
            // Exactly what the software watchdog does on a wedged loop: relay
            // is CLOSED (high), then open_relay() drives it low and abort()
            // ends the process (NOT a panic - the panic hook does not run). The
            // pin must read low afterward, proving the watchdog opens the relay.
            failsafe::arm(pin); // maps the GPIO block for open_relay
            unsafe { failsafe::set_output_high(base, pin) };
            println!("SOFTKILL before={}", unsafe { failsafe::read_level(base, pin) });
            failsafe::open_relay(); // the watchdog's action
            println!("SOFTKILL opened={}", unsafe { failsafe::read_level(base, pin) });
            std::process::abort();
        }
        _ => {
            eprintln!("usage: failprobe sethigh|read|armpanic|softkill");
            std::process::exit(2);
        }
    }
}

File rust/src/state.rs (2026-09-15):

//! Protection state machine.
//!
//! Pure logic - no I/O, no clock of its own. Time comes in as a parameter so
//! the whole thing is testable without hardware or sleeping.
//!
//! The safety rules hold regardless of mode:
//!   - the contactor is normally open; anything that stops this code opens it
//!   - voltage limits are never bypassed, not even by a manual start
//!   - losing the meter stops the pump; running blind is never safe

use serde::{Deserialize, Serialize};

use crate::meter::Reading;
use crate::settings::Settings;

#[derive(Debug, Clone, Copy, PartialEq, Eq, Serialize, Deserialize)]
#[serde(rename_all = "lowercase")]
pub enum Mode {
    /// Start whenever conditions are safe, restart after transient faults.
    Auto,
    /// Sit at Ready until a human says go.
    Manual,
    /// Contactor held open. Safe to work on.
    Off,
}

impl Mode {
    pub fn label(self) -> &'static str {
        match self {
            Mode::Auto => "AUTO",
            Mode::Manual => "MANUAL",
            Mode::Off => "OFF",
        }
    }
}

#[derive(Debug, Clone, Copy, PartialEq, Eq, Serialize)]
#[serde(rename_all = "lowercase")]
pub enum State {
    /// Mode is Off. Nothing will start the pump.
    Off,
    /// Conditions are not safe. Voltage outside the band.
    Waiting,
    /// Everything is fine. In Manual, waiting for a human.
    Ready,
    /// Confirming stability before closing the contactor.
    Starting,
    /// Contactor closed, water flowing.
    Running,
    /// Something went wrong. Will retry when conditions return.
    Tripped,
    /// Well is dry. Resting so it can recover.
    Lockout,
    /// Cannot read the meter. Refusing to run blind.
    Fault,
}

impl State {
    pub fn label(self) -> &'static str {
        match self {
            State::Off => "OFF",
            State::Waiting => "WAITING",
            State::Ready => "READY",
            State::Starting => "STARTING",
            State::Running => "RUNNING",
            State::Tripped => "STOPPED",
            State::Lockout => "WELL RECOVERING",
            State::Fault => "METER FAULT",
        }
    }

    pub fn contactor_closed(self) -> bool {
        matches!(self, State::Running)
    }
}

#[derive(Debug, Clone, Copy, PartialEq, Eq, Serialize)]
#[serde(rename_all = "snake_case")]
pub enum TripReason {
    OverVoltage,
    UnderVoltage,
    OverCurrent,
    DryRun,
    /// A hand-started run hit its time limit with nobody to end it.
    MaxRun,
    MeterLost,
    Manual,
}

impl TripReason {
    /// Full name, for the log and the dashboard.
    pub fn label(self) -> &'static str {
        match self {
            TripReason::OverVoltage => "OVERVOLT",
            TripReason::UnderVoltage => "UNDERVOLT",
            TripReason::OverCurrent => "OVERCURRENT",
            TripReason::DryRun => "DRY RUN",
            TripReason::MaxRun => "MAX RUN",
            TripReason::MeterLost => "METER LOST",
            TripReason::Manual => "STOPPED BY HAND",
        }
    }

    /// Plain-language line for the LCD, in the operator's words rather than
    /// the machine's. Every one fits inside 20 columns.
    pub fn plain(self) -> &'static str {
        match self {
            TripReason::OverVoltage => "volts went too high",
            TripReason::UnderVoltage => "volts dropped low",
            TripReason::OverCurrent => "pump pulled too much",
            TripReason::DryRun => "pump is not lifting",
            TripReason::MaxRun => "ran the full time",
            TripReason::MeterLost => "lost the meter",
            TripReason::Manual => "you pressed the red",
        }
    }

    /// Headline word, guaranteed short enough to sit beside "STOPPED".
    pub fn short(self) -> &'static str {
        match self {
            TripReason::OverVoltage => "HIGH VOLTS",
            TripReason::UnderVoltage => "LOW VOLTS",
            TripReason::OverCurrent => "OVERLOAD",
            TripReason::DryRun => "NO WATER",
            TripReason::MaxRun => "TIME UP",
            TripReason::MeterLost => "NO METER",
            TripReason::Manual => "BY HAND",
        }
    }
}

#[derive(Debug, Clone, Serialize)]
pub struct Event {
    pub at: String,
    pub reason: String,
    pub detail: String,
    pub volts: f32,
    pub amps: f32,
}

/// What the operator asked for, from a button or the dashboard.
#[derive(Debug, Clone, Copy, PartialEq, Eq)]
pub enum Command {
    Start,
    Stop,
    SetMode(Mode),
    Reset,
    ClearLockout,
}

/// Why a start request was refused. Shown verbatim to the operator, so it
/// has to explain itself without reference to a manual.
#[derive(Debug, Clone, PartialEq)]
pub enum Refusal {
    ModeOff,
    NotReady(String),
    InLockout(u64),
    AlreadyRunning,
}

impl Refusal {
    pub fn message(&self) -> String {
        match self {
            Refusal::ModeOff => "Mode is OFF - switch to MANUAL first".into(),
            Refusal::NotReady(why) => format!("Not safe to start: {why}"),
            Refusal::InLockout(mins) => {
                format!("Well is recovering - {mins} min left. Hold RESET to override.")
            }
            Refusal::AlreadyRunning => "Already running".into(),
        }
    }
}

fn log_forgive(remaining: u32) {
    println!("dry strike forgiven after a clean run, {remaining} remaining");
}
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

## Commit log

2026-09-15 Solar pump guard: pumpd controller, level-sensor board, hotspot and docs
    A Raspberry Pi Zero W running pumpd (Rust) keeps a 150 V solar water pump
    inside its safe voltage window, restarts it after transient faults and runs
    it from the well and tank levels. This repository holds the controller, the
    level-sensor board, the Pi hotspot setup and the design and build notes.
    [board2.kicad_pcb, board2.kicad_sch, pump-controller.fzz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]
2026-09-15 README: add a disclaimer
    Personal hobby project shared as-is, no affiliation or endorsement, 150 V DC hazard, no warranty.
